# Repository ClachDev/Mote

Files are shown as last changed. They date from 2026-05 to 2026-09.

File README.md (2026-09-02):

# Mote




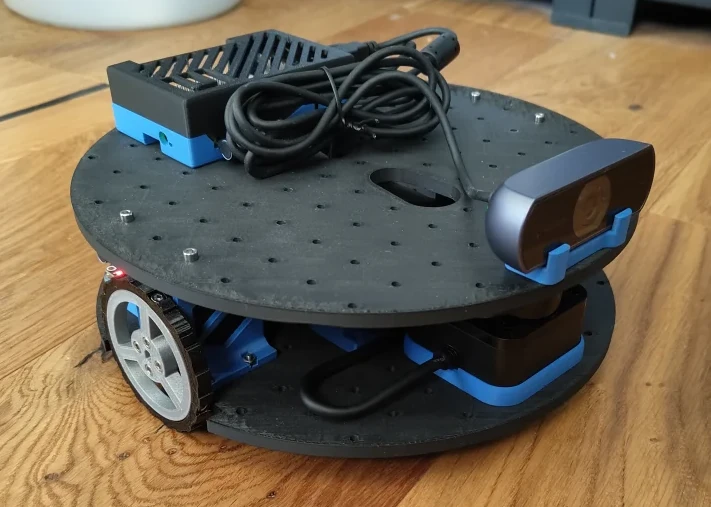
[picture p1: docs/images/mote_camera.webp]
Mote with camera


This readme covers the basics of Mote and how to use it. The full user docs including build instructions, etc, can be found [here](https://clachdev.github.io/Mote/).

## *Mote*vation (I'm sorry I had to!)

While working on some libraries I really needed a simple robot platform to test
them out on. There are some existing platforms but they are either too expensive
(turtlebot 3), or much too expensive (turtlebot 4). Some are cheap but lack
sensors (LeKiwi).

When I started out in robotics there was a [$50
robot](https://www.societyofrobots.com/step_by_step_robot.shtml) project I
followed. That was made for a different age but I figured why not see how
cheaply I can make a fully functioning robotics platform for today's enthusiasts.

The main factors I've engineered for are:

1. it must be as **cheap** as operationally possible - if it isn't affordable the
   project loses purpose.
2. it must be able to run **ROS** - you should be able to use this platform to run a
   normal ROS stack to map and navigate around a home or office.
3. it must be compatible with cutting edge PhysicalAI platforms like **LeRobot** -
   ROS is good but the future requires experimentation
4. it should follow the [Open Robotic
   Platform](https://openroboticplatform.com/designrules) standard - robots are
   more fun if you tinker about and add arms.

I've taken a lot of inspiration from projects like
[LeKiwi](https://github.com/SIGRobotics-UIUC/LeKiwi) which aim to be accessible
and [ORP](https://openroboticplatform.com/) which wants interoperability.

Apart from allowing me to test algorithms, I also want Mote to be a comparison
platform between classical ROS/Nav2 navigation and learned policies via
[LeRobot](https://github.com/huggingface/lerobot).

Finally, I also want to take this project further than just getting a robot running.
I want to use it to explore and act as a reference for what a full robotics
stack might look like: versioned maps, zones, remote operation, and maintaining
a multi-robot fleet.

See [`design/`](design/) for hardware design decisions, requirements, and bill
of materials.

## Hardware

The main hardware components are below with the Raspberry Pi and the battery
being the biggest cost factors (see [the BOM](design/BOM.md) for the full
hardware list).

- Raspberry Pi 5 (4GB) - Linux so we can run ROS, 4GB because memory is crazy expensive these days
- 5V USB-C power bank (slim form factor, ≥85W dual output) - Easy, cheap, and simple to integrate power supply
- 2× Feetech STS3215 servo - this simplifies our logic and standardises on components used by the [SO-101 arm](https://github.com/TheRobotStudio/SO-ARM100)
- Waveshare Serial Bus Servo Driver Board - Needed to connect servos to the pi.
  If using the SO-101 arm you can share a single board.
- SLAMTEC RPLIDAR C1 - The cheapest LIDAR I could find.
- USB webcam - Need some vision for LeRobot to function. Also helps with teleoperation.

I've tried to keep as many of the components 3D printed as possible to keep it
accessible. In theory some parts of the chassis can be CNC'd but I don't have
the ability to test and iterate on that right now.

## Software

Built with ROS2 Jazzy, managed via [pixi](https://pixi.sh). This gives us a nice
way to package everything up without worrying about ecosystem concerns — no
system ROS install needed, on the Pi or your workstation.

| Package | Purpose |
| --- | --- |
| [`mote_bringup`](mote_bringup/) | Launch files, site management, health monitoring, provisioning, etc |
| [`mote_description`](mote_description/) | URDF robot model and `robot.yaml` |
| [`mote_hardware`](mote_hardware/) | ros2_control hardware interface |
| [`mote_nav`](mote_nav/) | Nav2 plugins |
| [`mote_perception`](mote_perception/) | Image processing pipeline (needs a separate "inference" machine) |
| [`mote_tasks`](mote_tasks/) | Behaviour-tree task layer |
| [`mote_arm`](mote_arm/) | SO-101 arm driver |
| [`mote_fleet`](mote_fleet/) | Fleet control plane: fleet server, operator dashboard, map registry |
| [`mote_simulation`](mote_simulation/) | Gazebo sim, a world ladder, and the smoke test (workstation only) |

I'm trying to keep all dependencies from
[Robostack](https://robostack.github.io/index.html) or `conda-forge`. Anything
else belongs as a git submodule moving to either `conda-forge` or the
`prefix.dev/mote` channel once condafied/pixified.

## Build & Setup

### Prerequisites

- A Raspberry Pi 5 running 64-bit Linux (Ubuntu 24.04 or Raspberry Pi OS
  Bookworm both work) - set up with [Raspberry Pi
  Imager](https://www.raspberrypi.com/software/) -> Raspberry Pi OS Other ->
  Raspberry Pi OS Lite.
- [pixi](https://pixi.prefix.dev/) installed. Everything else (ROS 2 Jazzy,
  Nav2, drivers) is pulled in by pixi, so you don't need a system ROS install.
- The robot assembled with the servos and sensors wired to the Pi.

**Note:** The build commands (1 and 2) can be run on your developer machine for
testing, but 3 onwards requires the real hardware connected so must be run on
the Pi.

### 1. Clone

```bash
git clone --recurse-submodules https://github.com/ClachDev/Mote
cd Mote
```

(Forgot `--recurse-submodules`? `pixi run submodules` fetches them afterwards.)

### 2. Build

```bash
pixi run build
```

If you run these on your developer machine, sync the code to the Pi with
`pixi run sync`.

### 3. Setup Pi

There are a few setup tasks that must be run on the Pi before first use. These
set up udev rules, systemd services, and other configuration. It should only
need to be run once.

```bash
pixi run setup
```

### 4. Configure the servos

The drive wheels are expected at servo IDs **7** (left) and **9** (right) at
1 Mbaud. Fresh Feetech STS3215 servos ship as ID 1, so you'll need to assign
IDs before first use. Run the guided setup and connect one servo at a time when
prompted:

```bash
pixi run setup-ids
```

### 5. Map, then drive

The stack is split into two phases: an initial SLAM mapping phase and then a
non-SLAM drive phase.

To use SLAM to generate a map:

```bash
pixi run mapping   # bringup + SLAM: drive around (teleop or nav goals) to build a map
pixi run save-map  # save the map + posegraph into the active site
```

With a map saved you can just run the robot stack (no slam):

```bash
pixi run robot     # bringup + Nav2: drive the saved map autonomously
pixi run teleop    # Manual keyboard teleoperation, any time
```

You can also run a Foxglove desktop to connect to the robot over websocket at
`ws://<robot-id>:8765`. The layout is defined in
`mote_bringup/foxglove/mote.json`.

Maps live in **site bundles** under `~/.mote/sites/`.

**Congratulations! At this point you should have a working robot stack: maps,
SLAM, Nav2, and teleop.**

The longer version of all of the above — provisioning a clean Pi, what a site
bundle holds, the systemd services, naming zones and running missions — is
[Getting started](https://clachdev.github.io/Mote/getting-started/) on the docs
site.

## Simulation (no hardware required)

A Gazebo simulation of Mote runs the same controllers, same scan pipeline, and
crucially the *same launch files* as the real robot, so nothing can drift
between sim and hardware. The sim dependencies live in a separate pixi
environment so the robot install stays lean:

```bash
pixi run sim            # headless gz + robot + controllers
pixi run sim-test       # ~20 s headless smoke test (drive + odom + scan + map)
pixi run -e sim -- gz sim -g   # optional: attach the Gazebo GUI
```

The worlds in `mote_simulation/worlds/` form an easy-to-hard ladder, selectable
with `world:=` (e.g. `pixi run sim world:=hospital_world.sdf`):

- **`mote_world.sdf`** (easy) — a simple walled room; the default and the
  `sim-test` world.
- **`office_world.sdf`** (medium) — a corridor of identical rooms that
  stresses localisation.
- **`hospital_world.sdf`** (hard) — a ~58×38 m hospital with a looping
  corridor grid, ~50 rooms, and clutter.

## Perception

Rather than add a £150 RGB-D camera to the build, I've been trying to make use of a
single cheap webcam plus some smart vision models. The perception stack is
mostly offloaded to a separate "inference server" which runs somewhere with
access to a (cheap) GPU. This allows us to extract depth, tag objects, and
generally navigate as if we had a full 3D camera on board.

- **Depth Anything V2** — monocular depth, rescaled against the lidar per frame,
  feeds Nav2 a point cloud of the low obstacles the lidar plane can't see.
- **Open-vocabulary** — "red mug" becomes a map pose for the fetch
  mission, with no training.

I'm still experimenting with this to see how far we can push it. How the
inference machine is chosen, deployed and scaled — and what the robot does when
it isn't there — is
[The inference server](https://clachdev.github.io/Mote/inference-server/).

## SO-101 Follower Arm

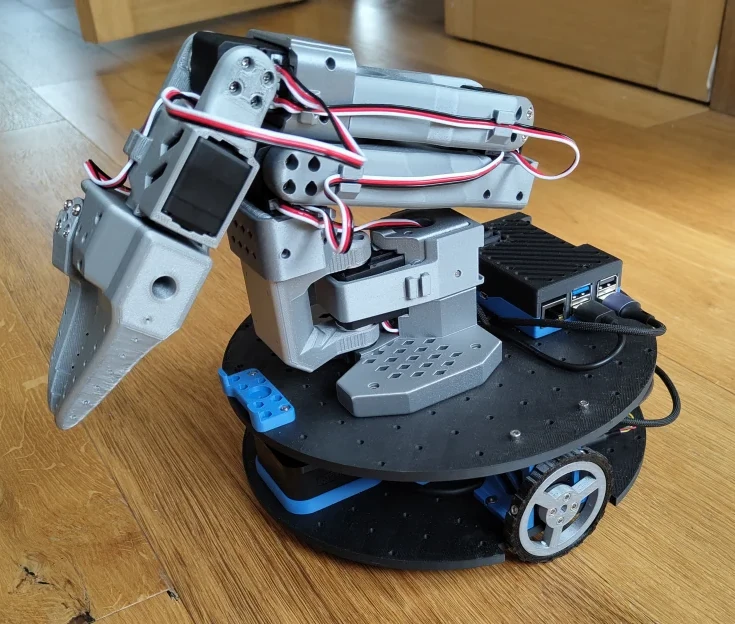
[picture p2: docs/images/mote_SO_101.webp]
Mote with SO-101 arm


The chassis is compatible with the [SO-101 follower
arm](https://github.com/TheRobotStudio/SO-ARM100) via the ORP mounting grid and
a custom base (see the SO-ARM100 project for the arm's BOM and assembly). The
arm shares the drive wheels' servo bus, so it needs no extra electronics.

I've started integrating it into ROS in [`mote_arm`](mote_arm/), covering the
driver, per-joint jogging, guided calibration that measures each joint's real
travel, and taught named poses.

## Fleet

I'm currently working on the beginnings of a fleet layer based on Tailscale and
MQTT. This is heavily work in progress but here's a little preview:

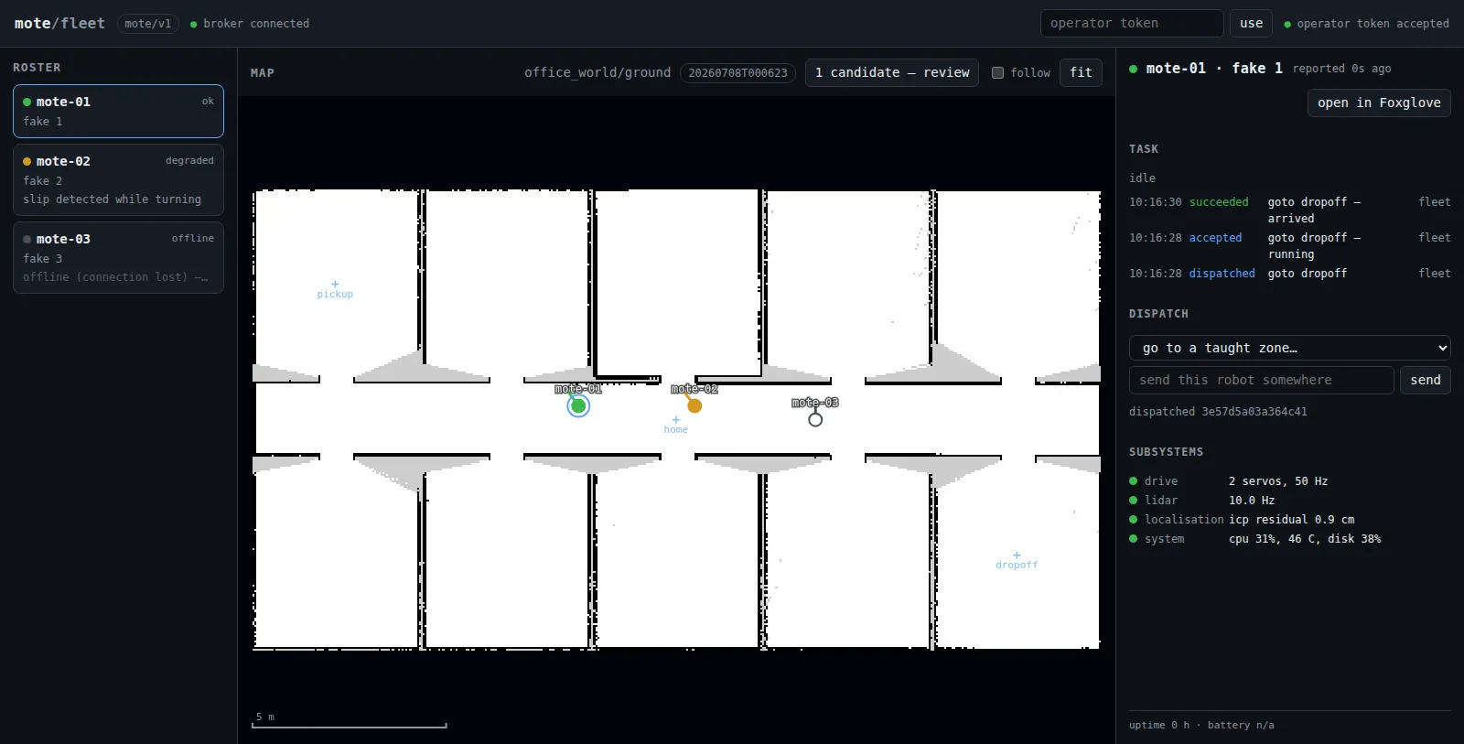
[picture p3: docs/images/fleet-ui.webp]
Fleet dashboard


The operator's side of it — overlay, enrollment, the dashboard, dispatch and
the map registry — is the
[fleet runbook](https://clachdev.github.io/Mote/fleet/).

## Contributions

This project is still in its early stages and I'm happy to accept contributions
of any kind. AI _aided_ contributions are also welcome but only if you can explain
and vouch for every change!

A [pre-commit](https://pre-commit.com/) config handles quick hygiene checks,
shell linting (shellcheck) and Python error checking (ruff). Enable it once per
clone, and it runs automatically on commit:

```bash
pixi run lint-install   # wire it into .git/hooks (one time)
pixi run lint           # or run across the whole tree manually (~1 s)
```

The [docs site](https://clachdev.github.io/Mote/) is built from this repo with
mkdocs, and mounts each package's own README rather than copying it — so
documentation is edited beside the code it describes:

```bash
pixi run docs           # live-reloading site on http://127.0.0.1:8000
pixi run docs-build     # what CI runs, with --strict
```

## Sponsorship

If you want to help me test new sensors or components to lower the cost even
further please consider sponsoring the project and I'll recognise you or your
company here!

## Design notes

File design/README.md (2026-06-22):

# Mote Design

## Design Decisions

### Chassis diameter: 235mm

The chassis uses a 235mm circular plate, adapted from the [ORP 360mm circular
plate](https://openroboticplatform.com/part:12). 235mm fits comfortably on a
standard 256mm 3D printer bed and gives a good outer hole layout from the ORP
grid — 240mm places holes right at the plate edge, and 250mm+ would be tight on
the bed. All components fit within the 235mm footprint, and the power bank
(152mm longest dimension) fits comfortably within the circle.

### Power: 5V only

Mote standardises on 5V (USB-C power bank) and does not offer a 12V variant.
The 12V config requires a DC-DC converter to power the Pi, adding cost and
complexity. A power bank outperforms a typical 12V Li-ion pack on
capacity (~100Wh vs ~60Wh), charges via standard USB-C, and has a built-in BMS.

The power bank directly connects to the Pi (USB-C to C) and the MCB (USB-C to C
to DC).

### Power bank form factor

The power bank is sandwiched between the two lower chassis layers to keep the
centre of mass low. The servo height is 45.2mm and the lidar is 41.3mm. For some
extra space and nice numbers I've buffered the standoffs to 50mm. This is then
the limiting factor in choosing a power bank. I've found that availability
changes depending on country so the most important thing to look for is a height
less than 50mm, and two USB-C ports. I found that with the UGREEN 140W bank
which advertises 100W on In/Out1 and 45W on Out2, I need to connect the MCB to
Out1 to stop them stalling. The Pi runs fine on the 45W port.

## Requirements

- Only two motors with differential drive. This matches real robots more closely
  than the three motors LeKiwi has.
- Normal wheels, not holonomics. Those are noisy and expensive.
- The wheels should be centered and inset so the footprint is circular.
- The chassis should follow the [ORP](https://openroboticplatform.com/) standard
  for interoperable parts.
- Standard sensor configurations
  - Camera
  - Lidar
- It should use "standard" parts, i.e. either Dynamixel or Feetech servos.
- The chassis should be compatible with the SO-101 arm from TheRobotStudio.
- Mote is intended as a comparison platform between the classical ROS/Nav2
  navigation approach and the LeRobot learned policy approach.

## Bill of Materials

See [BOM.md](BOM.md).

## Build guides

- [WIRING.md](WIRING.md) — connections, power topology and budget, IMU pinout.
- [ASSEMBLY.md](ASSEMBLY.md) — print settings per part and assembly steps.

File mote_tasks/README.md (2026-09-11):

# mote_tasks

The task layer: behaviour trees ([py_trees](https://py-trees.readthedocs.io))
that sit on top of Nav2 and sequence missions. Two missions today — *fetch*,
the skeleton of "pick things up off the floor and take them somewhere", and
*goto*, place-based navigation ("go to the kitchen"):

```
fetch (Sequence)
├── wait_for_task      idle until a command arrives
├── acquire_object     zone target: pass through; label target: ask the detector
├── drive_to_object    Nav2 NavigateToPose to the object pose
├── pick               stub — the SO-101 arm slots in here
├── drive_to_drop      Nav2 NavigateToPose to the drop pose
└── place              stub

goto (Sequence)
├── wait_for_task      idle until a command arrives
└── drive_to_zone      Nav2 NavigateToPose to the zone's pose
```

`task_server.py` hosts both trees and dispatches on the command's first word
(`fetch` / `goto`); an unknown word is rejected. `WaitForTask` and the shared
`task` blackboard key live in `trees/common.py`.

py_trees is pure Python (a pixi PyPI dependency); the ROS glue is ours and
deliberately small: `task_server.py` ticks the tree on a timer, and
`behaviours/nav.py` wraps the Nav2 action client as a behaviour. There is no
py_trees_ros dependency (it isn't packaged for robostack, and this glue is
~100 lines).

## Running

```bash
# Terminal 1: sim with SLAM + Nav2 (no saved map needed)
pixi run sim-mapping

# Terminal 2: the task server (zones default to mote_world coordinates)
pixi run tasks use_sim_time:=true

# Terminal 3: give it a job, watch the status
pixi run -- ros2 run mote_tasks mission --list      # what it will accept
pixi run -- ros2 run mote_tasks mission fetch target=pickup destination=dropoff
```

On the real robot, run `pixi run tasks` alongside `pixi run robot`. Zones
belong to the active site (see the Sites section in CLAUDE.md). Geometry gets
there three ways: `pixi run save-zone <name>` captures the pose the robot is
standing at, `pixi run segment-map` reads room outlines off a saved map, and
the fleet dashboard's zone editor places them on a candidate revision, which a
promotion then hands to every robot at the site. Only `save-zone` proves the
pose is reachable, by having driven to it; the other two put a coordinate on
the map and leave that to the planner. `tasks_launch.py` resolves the active
site's zones automatically, falling back to the committed
`config/zones.default.yaml` (which also documents the format).

## Zones, and "go to the kitchen"

A **zone** is the one named-place concept: a pose in the map frame that the
robot can navigate to. `fetch` uses zones as its `pickup`/`dropoff`
waypoints, and `goto <zone>` drives to any of them — `goto kitchen`,
`goto home`, whatever is in the table. A zone can *optionally* carry an **area
footprint**, which turns it from a bare waypoint into something that also
answers "am I inside it?". That footprint is just optional metadata on the
single zone concept — not a second kind of thing — so there's one loader
whatever wrote the file.

A floor stores this in one `zones.yaml`, and the floor owns it: a zone is a
coordinate in the floor's frame — a fact about the building — where a map
revision is an estimate registered into that frame.

```yaml
frame_id: map
zones:
  pickup:  {x: 1.8, y: -1.5, yaw: 0.0}      # bare waypoint
  kitchen: {x: 2.0, y: 2.0, radius: 1.5}    # room: pose + circular footprint
  ward:    {x: 6.0, y: 1.0,                 # room: pose + outline
            polygon: [[4, 0], [9, 0], [9, 3], [4, 3]]}
```

`goto kitchen` navigates to the pose; success is exactly Nav2 reaching it —
the footprint isn't needed for `goto`. `zones.load_zones(path)` returns
`{name: Zone(name, pose, footprint)}`, and `zones.containing(zones, x, y)`
answers "which zone am I in?" (nearest-pose first) using the footprints.

### Circles and polygons

A `radius` is the simple default — one number, and `pixi run save-zone <name>
--radius R` writes it along with the pose. It only describes a roughly round
room, though. A real ward is a rectangle, a ward with an ensuite is an L, and a
corridor stretch is a long thin box; sizing a circle to fit inside one of those
leaves most of the room outside the zone, and sizing it to cover the room
spills into the neighbours. Concretely, the hospital world's wards are 4.7 x
5.6 m — the `radius: 1.5` circle they used to carry claimed 7.1 m² of a 26.5 m²
room, so standing 2 m inside the kitchen answered "you are in no zone".

A `polygon` is a list of `[x, y]` vertices in the file's `frame_id`, closed
implicitly, in either winding order, and may be concave — membership is a ray
cast, not a convex-hull test. A zone carrying both keys uses the polygon.

Polygons do not come from driving. `pixi run segment-map` reads them off a
saved map, and the fleet dashboard's zone editor draws and drags them on a
candidate revision — which is also why a polygon zone may omit `x`/`y`: the
loader then derives a pose guaranteed to lie inside the outline (the centroid,
or, when the shape is concave enough that its centroid falls outside, the
middle of the widest span through it). Where a pose *is* given it always wins,
which matters: in the hospital wards the room centre is occupied by a bed, so
the pose is the doorway approach.

Because polygons arrive from a different direction than poses do, re-capturing
a room's pose with `pixi run save-zone <name>` keeps whatever footprint the
zone already had; passing `--radius R` is the deliberate way to replace it.
Zones are written into the active site's floor (`site info` shows the zone
count, how many have a footprint, and how many names have no geometry here at
all), or the legacy `~/.mote/zones.yaml` when no site is active.

## Interface

All three topics are `std_msgs/String` carrying JSON. A custom message would
have bought type-checking inside the ROS graph and cost the property that
matters more: the fleet agent forwards these payloads to MQTT byte for byte, so
there is one definition of the wire and the bridge cannot reinterpret it.

- `task/capabilities` — a **capability/v0 capability set**, published latched:
  what this robot can be asked to do, with a JSON Schema per input.
  `mote_tasks/capabilities.py` is the authority. Two keys, both from the
  specification's standard registry:
  - `goto` with `{"target": "<zone>"}` — drive to a named zone's pose.
  - `fetch` with `{"target": "<zone or label>", "destination": "<zone>"}` — a
    `target` matching a zone name drives straight there; anything else is an
    **open-vocabulary object label** (underscores become spaces, so
    `red_box` looks for "red box") resolved by the perception stack's detector
    — run `pixi run perception` (the node) and `pixi run inference` (its
    server) alongside the mission (see mote_perception's README, L2).
- `task/command` — a **mission/v0 mission command**: a capability key, a typed
  input, and a correlation id the dispatcher chose.
- `task/status` — a **mission/v0 mission status** per transition:
  `dispatched` (published by the agent) / `accepted` / `succeeded` / `failed` /
  `rejected`, the last two carrying a typed `failure`.

The failure is the point of the typing. `rejected` says `unknown_capability`,
`invalid_input` (naming the property), `busy` (naming the mission holding the
lane), `precondition` or `unresolved_zone` (carrying zone/v0's own reason);
`failed` says `obstructed`, `unreachable`, `timeout` or `internal`, and the
behaviour that failed is what decides which — see `trees/common.py`'s
`report_failure`. Each carries `recoverable`, so a dispatcher retries or does
not without reading prose.

**This node owns the lane.** One mission at a time per lane; a second is
rejected with `busy`. It also evaluates the capability's blocking preconditions
before accepting — `localized` wants a `map`→`base_link` transform, `zone_known`
wants the zone to resolve — and enforces `max_duration_s`, failing a mission that
overran with `timeout`. An unmet *non-blocking* precondition is reported in
`warnings` on the `accepted` status rather than refusing, so a mission that
started degraded is visible.

Label missions go through `behaviours/perception.py`'s `AcquireObject`: it
publishes the label to `detect/labels`, waits for a matching detection on
`detected_objects` (vision_msgs/Detection3DArray, map frame), and writes a
**standoff goal** — 0.4 m short of the object, facing it — to the same
`object_pose` blackboard key the zone path fills in directly. The rest of the
tree cannot tell the difference. The label is cleared on the way out so the
detector idles between missions.

## Where this goes

- **Search**: `acquire_object` currently needs the object visible from where
  the robot stands; a search behaviour (spin in place, tour zones) slots in
  ahead of it.
- **Arm**: `pick`/`place` stubs become real behaviours talking to the SO-101
  (same STS3215 bus as the wheels).
- New missions get their own tree under `trees/`, composed from the shared
  behaviours.

## Testing

`pixi run test` runs the tree tests against a mock `navigate_to_pose` action
server — `test/test_fetch_tree.py` (a full fetch tick), `test/test_fetch_object.py`
(fetch-by-label against a mock detector), and `test/test_goto_tree.py` (a goto
tick, plus command dispatch) — and the pure parser/loader tests
(`test_parse_command.py`, `test_goto_command.py`, `test_zones.py`, which covers
zone footprints and `containing`). No Gazebo, Nav2, or detection server needed.

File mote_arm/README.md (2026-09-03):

# mote_arm

Bring-up for the **SO-101 follower arm**: joint-state publishing, safe
joint-level control, and bench tools. This is the foundation for teleop /
episode recording and for replacing the fetch tree's pick/place stubs. There is
**no leader arm** — nothing here assumes leader-follower teleop.

## Stack decision: direct Feetech control (not LeRobot)

The task weighed **LeRobot** (native SO-101 support, calibration flow, dataset
format) against **direct Feetech control** (reuse the existing SCServo/servo
stack). We chose direct Feetech control:

1. **Same servos as the wheels.** The SO-101 uses Feetech STS-class servos on a
   serial bus — exactly what `mote_hardware` already drives via the vendored
   SCServo SDK. Position control, torque enable/disable, and feedback are a
   handful of register reads/writes we already understand. Reuse beats a new
   stack.
2. **LeRobot fights the lean Pi environment.** LeRobot pulls in `torch` and a
   large ML stack. The repo deliberately keeps `torch` *off* the Pi — depth and
   detection inference run in separate off-board `inference` pixi envs. Pulling
   that onto the Pi purely to move servos over serial is disproportionate. Our
   only new dependency is `feetech-servo-sdk` (`scservo_sdk`) — pure Python,
   aarch64-clean, the same SDK LeRobot itself uses under the hood, so this does
   not foreclose a LeRobot path later.
3. **Episode recording has a ROS-native path.** The repo already records
   provenance rosbags (`record_launch.py`). Teleop/episode capture can ride the
   same mechanism; we don't need LeRobot's dataset format to unblock the
   follow-up. If we later want that format for learning, we can convert bags or
   run LeRobot off-board.

   *That follow-up has since landed, and off-board is what it does* — the robot
   writes a stdlib-only capture and `tools/lerobot_export.py` converts it into a
   real `LeRobotDataset` in a linux-64 environment of its own. See
   [TELEOP.md](TELEOP.md). The decision above is unchanged: LeRobot is where the
   dataset goes, not where the arm is driven from.
4. **We can borrow the calibration flow without the framework.** LeRobot's
   `lerobot-calibrate` is two phases — write each servo's homing offset so
   mid-travel reads 2048, then record every joint's range in one sweep — and
   both are plain register operations on a bus we already drive. `pixi run
   arm-setup calibrate` implements that flow directly (see `BENCH.md`).

Everything hardware lives in `mote_description/config/robot.yaml` (`arm:`
section): the single source of truth for the port, baud, servo IDs, per-joint
soft limits, zero offsets, and direction.

### Why not an existing ROS 2 SO-101 stack?

Several exist and were reviewed (July 2026):

- [`legalaspro/so101-ros-physical-ai`](https://github.com/legalaspro/so101-ros-physical-ai)
  — the fullest arm stack: Feetech ros2_control driver, MoveIt 2, episode
  recording with LeRobot dataset export, torch isolated off the control path.
  Jazzy. But it is a **standalone arm on its own bus** and its teleop assumes a
  leader arm; we have neither.
- [`brukg/so_arm_100_hardware`](https://github.com/brukg/so_arm_100_hardware)
  — SO-100 ros2_control hardware interface; same standalone-arm shape.
- [`adityakamath/lekiwi_ros2`](https://github.com/adityakamath/lekiwi_ros2) —
  the closest platform to Mote (the LeKiwi mounts an SO-101 on a mobile base,
  and our servo IDs — arm 1-6, wheels 7/9 — follow its convention). As of this
  writing it drives the base and a pan-tilt payload only; its SO-101
  integration is planned, not shipped.

None of them address what dominates this package: the arm **sharing a serial
bus with the drive wheels** — bus ownership, ID collision, and the single-opener
guard. That problem has no shipped public solution, which is why `mote_arm`
exists rather than a dependency.

We are not outside this ecosystem either: `mote_hardware` builds on our fork of
[`adityakamath/SCServo_Linux`](https://github.com/adityakamath/SCServo_Linux)
(packaging fixes upstreamed, v1.0 packaged on the mote prefix.dev channel) —
the same SDK LeRobot and the stacks above sit on. Arm control has since folded
into `mote_hardware`'s ros2_control interface (below);
[`adityakamath/sts_hardware_interface`](https://github.com/adityakamath/sts_hardware_interface)
does the same job on the same SDK, with mixed position/velocity modes on one
bus, and remains the upstream to converge on — but it targets Kilted (we run
Jazzy), is not on rosdistro, and is a fast-moving single-maintainer WIP, so
adopting it now would trade a working stack for a moving one.

## Wiring: the arm shares the drive-wheel bus

Verified on the robot: arm servos are IDs **1–6**, the drive wheels are **7**
and **9**, and all eight are on the one `/dev/mote_servos` (CH343) bus. The arm
needs no udev rule of its own.

A serial port has no kernel-level exclusion, so a second opener is not refused —
it interleaves packets on the bus that *moves the robot*, and both openers see
corrupt replies. There is therefore exactly one process allowed to hold that
port, and **it is the controller_manager**: `mote_hardware`'s `MoteHardware`
exports velocity command interfaces for the wheels and position command
interfaces for the six arm joints, from one `open()`.

That is what lets the arm move *during* a mission, with Nav2 driving the wheels
at the same time — the point of the arm, and impossible while it lived in its
own process. Two guards keep the arrangement honest rather than merely
documented:

- **ID collision** — an arm ID equal to a wheel ID would send arm commands to a
  wheel. Rejected at load time in `mote_arm.config` *and* in `MoteHardware`, on
  both sides of the language boundary.
- **One opener only** — `MoteHardware::on_activate` scans `/proc` for another
  holder of the port and refuses to start, naming the PID; the read-only bench
  tools (`arm-setup check`, `arm-setup gains`) do the same through `mote_arm.bus`. So
  whichever starts first wins and the loser says why, instead of two processes
  quietly corrupting each other's traffic.

The bench tools still open the bus directly, so they still need the control
stack stopped (`pixi run kill`): `arm-setup check`, `arm-setup gains`, `arm-setup calibrate` and
`arm-setup offsets`. `arm-teleop` and `arm-pose` do not — they command the controller.

### Where the calibration enters

`zero`/`min`/`max` are measurements of one physical arm, so they live in
`$MOTE_HOME/arm.yaml` and robot.yaml carries only conservative placeholders
(see "`zero` and `home` are different things" below, and `arm-setup calibrate`).
The hardware enforces the soft limits, and the hardware reads them from the
URDF — so the URDF has to carry the *calibrated* numbers:

```
robot.yaml arm:  (defaults: ids, names, direction, gains)
        +
$MOTE_HOME/arm.yaml  (this arm's measured zero/min/max)
        |
        v  mote_arm.config.load() — the one implementation of the overlay
  launch_utils.resolved_arm()
        |
        v  written out, passed as xacro's `arm_config:=`
  <ros2_control> joint <param>s  ->  MoteHardware's clamp
```

xacro cannot resolve `$MOTE_HOME` or apply the overlay, so the launch does it
and hands over the answer. A bare `xacro mote.urdf.xacro` (for checking
generation) falls back to the packaged placeholders — never drive a calibrated
arm from that URDF, because calibration *moves the zero*, so the same radian
value names a different physical position.

## Where the arm lives in the control stack

```
robot.yaml (arm:)
   |
   +-- mote.urdf.xacro  -> <ros2_control> joints, one per arm servo, carrying
   |                       its id / soft limits / home / invert as <param>s
   |
   +-- mote_launch.py   -> arm_controller's joint list (never duplicated in
                           controllers.yaml)

controller_manager
   |-- diff_drive_controller   (active)    velocity -> wheels
   |-- joint_state_broadcaster (active)    /joint_states, wheels *and* arm
   \-- arm_controller          (INACTIVE)  position -> arm, on demand
```

`arm_controller` is a `JointTrajectoryController`, spawned **inactive**.
Activating it is what claims the arm's position command interfaces, which is
what makes the hardware enable torque — so "the arm is limp until something
asks it to move" is now a property of the control stack rather than a rule the
driver had to remember.

The hardware also spends the shared bus carefully, because the wheels are on
it: arm states are read one joint per control cycle (~8 Hz per joint at the
50 Hz update rate) rather than six reads every cycle, and arm goals go out as a
single sync-write packet, only when a goal actually changed. An idle arm costs
no bus traffic at all.

## Components

All bus I/O is isolated in `bus.py`; the config maths in `config.py` is
ROS-free and unit-tested (`test/`), so the safety-critical clamping and
conversions are verified without hardware.

| Piece | What it is |
|---|---|
| `config.py` | Parses the `arm:` section; encoder<->radian conversion + soft-limit clamping. |
| `bus.py` | `FeetechBus` — thin `scservo_sdk` wrapper (ping, read position/health, torque, position goal, homing offset). Lazy SDK import. |
| `control.py` | The one place that knows how to talk to `arm_controller`: single-point trajectories, and activation as the torque switch. |
| `cli.py` | The plumbing every arm CLI shares: strict argument parsing with ROS's own arguments cut out first, and a shutdown that stops spinning before it destroys the node. Both are properties that fail silently otherwise — see "Exits and arguments" below. |
| `arm_launch.py` (in `mote_bringup`) | Bench bring-up — the same controller_manager, URDF and `controllers.yaml` as a mission, without the lidar/camera/Nav2. `pixi run arm`. |
| `arm_check` (tool) | Standalone enumeration + health + zero snapshot. Read-only, but opens the bus: run with the control stack stopped. `pixi run arm-setup check`. |
| `calibrate.py` / `arm_calibrate` | Two-phase range calibration: sweep every joint at once, centre its zero, save limits to `$MOTE_HOME/arm.yaml`. Owns the bus: control stack stopped. `pixi run arm-setup calibrate`. |
| `arm_offsets` (tool) | Read/back up/restore/set the servos' position-correction offsets. The recovery path if a calibration is interrupted. `pixi run arm-setup offsets`. |
| `poses.py` / `arm_pose` | Teach and replay named poses, and narrow limits to a working envelope. `pixi run arm-pose save\|list\|go\|limits\|delete`. |
| `mock_arm` (node) | The control stack's interface — trajectory topic and `switch_controller` — with nothing behind it, plus an optional synthetic camera, so teleop, recording and replay run on a workstation. `pixi run arm-mock`. |
| **teleop + episodes** | Keyboard teleoperation and LeRobot-format episode recording — `teleop.py`, `arm_teleop`, `episode_record`, `episode_replay`, `tools/lerobot_export.py`. Its own doc: **[TELEOP.md](TELEOP.md)**. |

## Exits and arguments

Two things every arm CLI needs, both of which fail *quietly* when hand-rolled,
so they live in `cli.py` and nowhere else.

**Destroying a node that `spin()` still holds aborts the process.** The
executor is pulled out from under itself and the interpreter calls
`std::terminate`: exit 134, `terminate called without an active exception`,
after the tool has already done its work. The fix is ordering — shut the
context down, *join the spin thread*, and only then destroy — which is what
`cli.shutdown(node, spinner)` is for. Measured on this arm's CLIs with no
hardware attached: the jog CLI (stdin closed) and `arm-pose list` each aborted 3 of 3
runs before, and exited 0 on 3 of 3 after. It is not a rare race — with no
stack running to talk to, it reproduced every time. `test_cli.py` watches a
child process's exit status, because nothing in-process can catch an abort.

**ROS's arguments arrive mixed in with the tool's own.** `ros2 run` hands the
executable the whole command line, so a plain `parse_args` rejects
`--ros-args` outright (`arm-pose list --ros-args -p use_sim_time:=true` used to
die with "unrecognized arguments") while the usual workaround,
`parse_known_args`, silently discards anything it does not recognise — which on
a *safety* flag means a mistyped `--max-travel` or `--speed` does nothing and
says nothing, and the arm moves under the default instead. `cli.parse` cuts the
`--ros-args ... --` block out first and then parses what is left strictly, so
ROS arguments pass through and a typo is still an error.

## `zero` and `home` are different things

Worth stating plainly, because the two were both called "home" until 2026-07-28
and it confused an operator at the bench:

| Term | What it is | Where it lives |
|---|---|---|
| **zero** | The encoder count that reads 0 rad. After calibration, the *middle of the joint's travel*. | `robot.yaml`, `arm.joints[].zero` |
| **home** | A taught *pose*, normally the arm's rest position. Nothing to do with 0 rad. | `~/.mote/arm_poses.yaml` |

So the jog CLI's command to drive a joint to 0 rad was `zero`, not `home` (`home`
still works and says so), and `pixi run arm-pose go home` moves to the rest pose.

## Where the soft limits come from

**`pixi run arm-setup calibrate`**, in two phases — the same shape as LeRobot's
`lerobot-calibrate`:

```
pixi run arm-setup calibrate                        # sweep, then centre the zeros
pixi run arm-setup calibrate --skip-homing       # ranges only; writes nothing
pixi run arm-setup calibrate --joints wrist_roll # redo one joint
```

You sweep the joints; everything else is automatic.

**Phase 1 — record the ranges.** You move every joint to both of its mechanical
stops, in any order, while one live table records **all six at once**. One Enter
ends it. The band emitted is the swept range pulled **inward** by `--margin`
(0.05 rad), because a hard stop is where the operator stopped pushing — a soft
limit has to sit short of it.

**Phase 2 — centre the zeros.** Each joint's 0 rad is moved to the *measured*
middle of the range just swept, by writing the servo's position-correction
register (EEPROM, `SMS_STS_OFS_L/H`, address 31). The servo reports
`present = actual - offset`, so this re-centres the joint's whole travel inside
the 0–4095 encoder frame. The arm can be left wherever the sweep ended.

**Why the centre comes from the sweep.** LeRobot's `calibrate()` opens with a
single `input("Move {robot} to the middle of its range of motion and press
ENTER")` and takes every motor's zero from that one pose. It is an awkward,
unbalanced position to hold all six joints in, and eyeballing the middle is less
accurate than the measurement the sweep is about to take anyway.

That ordering is *load-bearing for them*, though, not incidental:
`record_ranges_of_motion` is a plain `min`/`max` over raw positions with **no
wraparound handling at all**. Centring first is what guarantees the sweep never
crosses 0/4095, which is what makes plain min/max safe. Sweeping first, as we do,
means the sweep *can* cross it — so `SweepRecorder` unwraps, and the centre is
recovered from the unwrapped stream. The trade is a small heuristic (a jump of
more than half a revolution between samples is a crossing, which no hand-moved
joint can produce at 20 Hz) in exchange for deleting the awkward step. It also
means a wrapped sweep is handled rather than silently mis-recorded.

LeRobot is Apache-2.0, so borrowing their code would be permitted with
attribution; none is copied here — only the shape of the flow.

**Centring is what makes the limits describable at all.** A joint whose travel
straddles the encoder's 0/4095 boundary has a raw min and max that say nothing
about its real span, and no zero/limit pair in that frame can express it —
`rad_to_counts` clamps at the encoder edge. Measured on the real arm, **two of
six joints did exactly that** (`shoulder_pan` and `wrist_roll`). There is no
software workaround: the servo's own goal register is 0–4095 too.

Offsets are **modular** — `present = (actual - offset) mod 4096`, so an offset of
3056 and one of −1040 command the same thing. An arithmetic result outside the
register's ±2047 is therefore folded, never rejected. (Rejecting one aborted a
real calibration run before this was understood.)

It opens the serial bus directly, like `arm-setup check`, so run it with the driver
stopped: the driver reports radians about the very zero being replaced, and the
arm has to stay limp throughout. It asks before releasing torque (an unsupported
arm falls) and again before the EEPROM write.

Four things it refuses to guess at, rather than emit plausible-looking numbers:

- **Travel beyond one revolution.** A continuously-rotating joint has no stops
  to calibrate against and fits no single-turn frame. Reported as its own case,
  because unlike a wrap there is no remedy — leave it out with `--joints`.
- **A range too short to survive the margin at both ends.**

**A continuously-rotating joint is only detectable if you rotate it past a whole
turn**, which is the one case refused above. Rotated less, it is indistinguishable
from a joint with stops, and no threshold below a full turn helps: it would miss
most real cases while firing on a long-but-stopped joint. LeRobot sidesteps this
by hard-coding the SO-101's `wrist_roll` as a full-turn motor and skipping its
range entirely. This arm's `wrist_roll` measures 5.88 rad — 94% of a turn — so
whether it has real stops is worth settling by hand; if it spins freely, exclude
it with `--joints` and drive it in relative terms.
- Under `--skip-homing` only, where the zero is not being moved: **an encoder
  wrap**, and **a zero the joint could never reach** (a band excluding 0 rad —
  the defect in the pre-calibration `shoulder_pan` limits, whose
  `[0.010, 0.229]` does not contain 0). Neither can arise from the centred path,
  where the zero *is* the middle of what was swept.

**If it stops partway, the arm is recoverable.** The offset register lives only
in the servo, so overwriting it destroys the previous value. Before the first
write, the existing offsets are snapshotted to `~/.mote/arm_offsets_backup.yaml`;
each servo is then written, verified by read-back, *and* checked to have moved
its reading by exactly the delta written, before moving to the next. Any failure
stops immediately, names the servos already changed, and points at
`pixi run arm-setup offsets restore`. (An earlier version wrote without a backup and
died mid-run on a dropped serial read — hence both the snapshot and the guard in
`FeetechBus._read`, which turns a short reply into `None` instead of an
`IndexError`.)

Taught poses do not have to be re-taught: they are re-expressed about the new
zeros by exactly the shift the calibration computed, so each still points where
it always did, and the previous file is kept as `.bak`. Only a pose that lands
outside the new soft limits is named — that one was taught somewhere the arm
cannot reach, which is a decision rather than an arithmetic problem.

**It saves the result to `~/.mote/arm.yaml`** — per-robot state, not the repo —
and says so in one line. The numbers are not reprinted: the swept ranges were on
screen a moment ago, the limits are those pulled inward by `--margin`, and the
file itself keeps each value next to the measurement it came from.

That location is the point. Zeros and limits are measurements of *one physical
arm*: two robots with identical hardware have different ones, and the packaged
`mote_description/config/robot.yaml` is shared by the whole fleet and read-only
once installed from a channel. So the package keeps the *design* — ids, names,
direction, gains, and conservative defaults for an arm that has never been
calibrated — and `mote_arm.config` overlays this robot's measured
`zero`/`min`/`max` on top at load time. Delete the file to fall back to the
defaults. It is the same rule as `~/.mote/camera_calibration.yaml` and the site
bundles: `MOTE_HOME` is per-robot, the package is shared.

The file carries the measurement alongside the value — swept range, sample
count, margin, and the `homing_offset` written to the servo, which exists
nowhere else and is the only record if a servo is swapped. Writes go through a
temporary file, and the result is validated through `ArmConfig` before it lands,
because this is what supplies the soft limits that stop the arm.

**Taught poses are migrated for you.** A pose is stored as radians about the
zero, so moving the zero changes which physical position each number names — but
the correction is exactly the shift the calibration just computed, so the poses
are rewritten rather than re-taught. They keep pointing where they always did,
and the previous file is kept as `.bak`. A pose that would land outside the new
limits is reported rather than silently clamped: that means it was taught
somewhere the arm can no longer reach, which is a decision, not an adjustment.

**One confirmation, at the EEPROM write.** Everything else follows from having
run the command: torque is released without asking (the arm is already limp
unless a driver was killed outright, which is detected by reading the torque
register), and the result is saved without asking, since saving it is what the
command is for.

### The servo's own goal-range limits, which are not the soft limits

There is a fourth place a limit can live, and it is the only one that is not in
a file. EEPROM registers 9 and 11 (`Min_Angle_Limit` / `Max_Angle_Limit`) fence
which goal positions a servo will accept. A goal outside the band is **refused
in silence**: no error, no status bit, no log line. The joint stops at the same
angle every time, in one direction only, whatever the load — which is precisely
what running out of torque looks like.

This arm arrived with five of six joints fenced inside their own travel, and it
cost an evening. `shoulder_lift` stopped dead at −0.865 rad against a
configured −1.7785, at 0% load, while the commanded position ran 0.8 rad past
it. Its `Min_Angle_Limit` read **1478**, and 1478 counts is −0.874 rad about a
zero of 2048:

```
joint            id    min   max   accepts (rad)      configured
shoulder_pan      1   1123  3079   -1.419 .. +1.582   -2.033 .. +2.033
shoulder_lift     2   1478  3859   -0.874 .. +2.778   -1.778 .. +1.778
elbow_flex        3    716  2941   -2.043 .. +1.370   -1.646 .. +1.646
wrist_flex        4    709  3075   -2.054 .. +1.575   -1.761 .. +1.761
wrist_roll        5      0   4095  -3.142 .. +3.140   -2.880 .. +2.880
gripper           6   2047  3510   -0.002 .. +2.243   -1.073 .. +1.073
```

**What set it: `lerobot-calibrate`, on the workstation, 2026-05-12.** The file
is still there —
`~/.cache/huggingface/lerobot/calibration/robots/so_follower/so101_follower.json`
— and its `range_min`/`range_max` are the six bands above to the count, beside
the `homing_offset` values the servos arrived with (2027, -1723, 1772, -1706,
-40, 1317). An earlier attempt sits next to it from the same morning
(`auldbot_arm.json`, 10:40) with `wrist_flex` still unswept at 0-4095.

LeRobot writes those registers from the range of motion it records, which is a
reasonable thing to do and is not what broke. **What broke is that
`arm-setup calibrate` then moved the zeros and left the fence where it was**, on
2026-07-28: a band in the corrected frame names different physical angles once
the offset under it changes, so the fence silently drifted onto the middle of
the joint's travel. Hence this tool writes the fence *and* the offset in one
run, and never one without the other.

Two of the six bands were already wrong when LeRobot wrote them, which is worth
knowing before trusting one. `wrist_roll` is unfenced because LeRobot hard-codes
the SO-101's `wrist_roll` as full-turn and skips its range. `shoulder_pan`'s
band is 760 counts narrower than its real travel, which is what an unwrapped
min/max `record_ranges_of_motion` yields for a joint whose sweep crosses 0/4095
— and `shoulder_pan` is one of the two joints here that do.

Two properties made it hard to see. The fence only binds under torque, so
`arm-setup calibrate` sweeps straight through it by hand and measures the full travel
— the calibration and the arm disagree, and only the arm is wrong. And the band
is compared against the *corrected* goal, so re-centring a zero moves what it
fences without changing a number anyone can read.

```
pixi run arm-setup limits show      # read-only: the band, in counts and radians
pixi run arm-setup limits clear     # hand every joint its whole 0-4095 range back
pixi run arm-setup limits restore   # write the as-found bands back
```

**The fence and the zero are now written by one run, and never one without the
other.** Phase 2 writes each joint's fence immediately after its own offset —
after, because the band is compared against the corrected goal and so means the
wrong angles until the frame has moved; immediately, because the pair is what
has to agree. Nothing is unfenced in between: a joint holds either its old band
or its new one, and the window where the two disagree is one bus transaction
wide. Both as-found sets are snapshotted first (`arm_offsets_backup.yaml`,
`arm_limits_backup.yaml`); neither exists anywhere else. `--skip-homing`
promises to write nothing to the servos, so it reports a cutting fence instead
of correcting it.

**The band written is the measured travel, not the soft limits** — wider by
`--margin` (0.05 rad) at each end. That is what makes it a backstop rather than
a second opinion: `arm.yaml` always binds first, so the fence can never be the
thing that stops the arm in ordinary use, and `arm-setup limits show` reporting a band
narrower than the configured one therefore means something is wrong rather than
meaning Tuesday. What it catches is a soft limit that has gone wrong — a
hand-edited `arm.yaml`, a URDF that never received one, a servo swapped under a
stale calibration — where the servo still refuses to drive past its own stops.

There is no `arm-setup limits set`. A *narrower* envelope belongs in `arm.yaml`, where
`arm-pose limits` already puts one and where three commands print it;
`arm-setup limits clear` exists to take the fence off while diagnosing, and `restore`
to put back whatever was found.

### Named poses, and narrowing the envelope

The base layer captures a map position by driving there and running
`pixi run save-zone`; the arm's analogue is `pixi run arm-pose`. Pose the limp
arm by hand, capture it, and later command it back:

```
pixi run arm-pose save reachy     # read-only capture of the current pose
pixi run arm-pose list            # taught poses, and how far the arm is from each
pixi run arm-pose go reachy       # the only command that moves; asks first
pixi run arm-pose limits          # emit limits spanning the taught poses
```

Poses live in `~/.mote/arm_poses.yaml` (`MOTE_HOME` overrides `~/.mote`) —
per-robot data, since a pose only means anything for one physical arm and its
calibration. A pose is recorded in radians about its joint's `zero`, so moving a
zero changes which physical position each number names — but `arm-setup calibrate`
applies exactly the shift it computed, so poses survive a recalibration without
being re-taught. Editing a `zero` by hand does not, and invalidates them.

`arm-pose limits` is **not** the calibration path. It widens *outward* from the
extremes of the taught poses, so it can only describe where the arm has already
been, and it never learns where the stops are: a joint that barely moved between
two poses gets a near-zero band. Its remaining use is the opposite direction —
**narrowing** to a working envelope on top of calibrated hard-stop limits, when
a task wants a joint held tighter than the mechanism allows. Take the hard stops
from `arm-setup calibrate` first; reach for `limits` only to pull them in.

The values committed in `robot.yaml` today still come from the old envelope
method, and are flagged as such in that file, pending a calibration pass on the
real arm (`BENCH.md` step 3).

`arm-pose go` prints the travel each joint will make and asks before moving.
There is no ceiling on the distance — see below for why the one there used to be
was removed.

It **streams** setpoints at 20 Hz rather than commanding the destination in one
jump, so the arm moves continuously at `--speed` (0.5 rad/s default) instead of
lurching between waypoints. Supervision is by *lag* — how far the arm trails the
setpoint it was given: sustained lag beyond `--max-lag` (0.15 rad) for
`--stall-time` means it is no longer keeping up, and the move stops where it is.
Measured lag on the full swing is a steady 0.07-0.10 rad.

`arm-pose go` and `arm-teleop` command `arm_controller`, so they run happily alongside
a mission. `arm-setup check`, `arm-setup gains`, `arm-setup calibrate` and `arm-setup offsets` open the
bus directly and so still need the control stack stopped — `MoteHardware`'s own
guard will refuse to start against them, and theirs will refuse to start against
it.

Lag is measured against `/joint_states`, which the hardware refreshes one arm
joint per control cycle to stay inside the bus budget it shares with the wheels,
so a stall is caught within a few setpoints rather than instantly.

**Whether the arm is held is read from the controller manager, not assumed.**
`go` leaves `arm_controller` active — that is what holding the pose means — so
the next command client starts against an arm that is already held.
`ArmControl` therefore asks `list_controllers` before its first switch, and
treats a STRICT refusal as success when the controller turns out to already be
in the state requested. Assuming `inactive` at construction made the *second*
`arm-pose go` of a session fail on every streamed setpoint: `Controller with
name 'arm_controller' is already active` / `Aborting, no controller is
switched!`, at 20 Hz. It also made the jog CLI's documented limp-on-exit silently
do nothing when something else had left the arm holding.

**A taught pose is stored reachable.** `save` clamps each joint into its soft
band and names the ones it held there. Posing by hand is posing a limp arm
against its stops, and the soft limits sit `--margin` (0.05 rad) inside those,
so a raw capture is routinely a fraction outside the band — measured at the
bench, `elbow_flex` 0.012 rad past and `gripper` 0.042 rad past. Stored raw,
such a pose can never be replayed: every `go` clamps it and says so, which is a
warning that arrives minutes late. A joint further out than the margin is
reported separately, because that means the arm and `arm.yaml` disagree about
where the limits are rather than that the operator leaned on a stop.

**`go` has no travel ceiling, and the one it had is gone.** `--max-travel`
defaulted to 0.35 rad, chosen when the packaged limits were the old `arm-pose
limits` envelope whose bands were ~0.2 rad — wider than a whole joint's range,
so it fired on nothing. Calibration gave the joints their real ~3.5 rad bands
and left it refusing the ordinary case: teach a pose, let go, watch the limp arm
fall to rest, replay.

Sizing it off the arm instead would have made it fire on nothing again, which is
worse than removing it: a flag, a help string and a test that all describe
nothing. And distance is not what makes a move risky once setpoints are
streamed. The arm advances at `--speed` whatever the distance, so a long move is
a slow move and not a violent one; `--max-lag` stops it if the arm falls behind;
the soft limits bound where it can go; and every move is confirmed unless
`--yes`. The distance limit was a proxy for the lurch that streaming removed,
and nobody removed the proxy.

`episode-replay` keeps a `--max-travel`, doing a different job: a long approach
there means the arm is not where the recording started, so the replay will not
reproduce it. That is a check on the episode, not on the motion.

## Torque policy

Nothing moves without an explicit command. The policy did not change when the
arm moved into ros2_control — it stopped being a rule the driver enforced and
became a consequence of who holds the command interfaces.

- **Bringup:** torque **OFF** — the arm is limp/back-drivable, and
  `arm_controller` is spawned inactive so nothing holds its interfaces. Have the
  arm physically supported or resting in a stable pose before power. A servo
  that fails enumeration, or cannot be *confirmed* in position mode (mode
  changes are verified by read-back, never blind-written to EEPROM), is excluded
  from control entirely: its state is still published, but it accepts no goals —
  in wheel mode a position goal is obeyed as a speed.
- **Taking hold:** activating `arm_controller` makes the hardware seed each
  joint's goal register with its *present* position and only then enable torque
  — the order that stops an arm snapping to a stale goal. It engages one joint
  per control cycle (~120 ms for all six) so no single realtime cycle pays for
  six read-plus-write pairs, and a joint whose position cannot be read stays
  limp rather than being driven against an unknown goal.
- **Letting go:** deactivating `arm_controller` (`arm-teleop`'s `SPACE`, or
  quitting it) drops torque immediately, inside the switch itself rather than
  on the next write — a component being torn down may never write again.
- **Shutdown:** deactivating the hardware stops the wheels and limps the arm.

Goals are soft-clamped to the per-joint limits from `robot.yaml` **in the
hardware**, on the far side of every client, so a trajectory controller, the jog
CLI and the task layer are all held to the same envelope. `arm-teleop` clamps again
client-side purely for immediate feedback.

## Control interfaces

- `/joint_states` (`sensor_msgs/JointState`) — published by
  `joint_state_broadcaster` for the wheels *and* the arm. robot_state_publisher
  animates the arm in TF from these (the joints are in the URDF; see
  `mote_description/urdf/mote.urdf.xacro`, `arm:=true`).
- `arm_controller/joint_trajectory` (`trajectory_msgs/JointTrajectory`) — a
  goal. `allow_partial_joints_goal` is on, so a single-joint trajectory is
  valid and the rest hold where they are.
- `arm_controller/follow_joint_trajectory` (action) — the same thing with
  feedback and cancellation; this is the seam the task layer's pick/place will
  use in place of its stubs.
- `controller_manager/switch_controller` — activate to hold, deactivate to limp.

## Physical note: the arm is mounted backwards (GitHub #2)

The camera and the arm fouled each other on the top plate. The arm is therefore
mounted **rotated 180 degrees**, which is option 1 of that issue: the camera
clears it — only just — and the price is reach in the forward direction.

Two consequences. `arm_mount_joint` in `mote.urdf.xacro` still carries
`rpy="0 0 0"`, so TF and RViz draw the arm facing the way it used to, not the
way it does; joint-space work (jog, taught poses, teleop, replay) is unaffected,
because none of it asks where the gripper is in the base frame, but anything
that does — a fetch standoff pose, an IK stack — would be 180 degrees out.
And the clearance is tight rather than comfortable, so re-check it after any
re-mount.

## Calibration

The committed `zero:` values are the arm's **as-found resting counts** read off
the robot, not measured mid-travel. A real calibration run showed why that is
bad: the parked pose sits within ~20 counts of a hard stop on `shoulder_lift`,
`elbow_flex` and `gripper`, so "0 rad" currently means "jammed against the
stop", and the committed bands (~0.2 rad) are a small fraction of the ~3.4–3.6
rad these joints actually travel.

See `BENCH.md` for the full runbook. In short:

1. `pixi run arm-setup check` — confirm every joint responds; note IDs.
2. `pixi run arm-setup calibrate` — sweep the joints, centre their zeros, save to
   `~/.mote/arm.yaml`. No rebuild: the file is read at load time, not compiled
   in. This sets `zero` *and* `min`/`max` together, which is the point: limits
   only mean something relative to the zero they were measured about.
3. Re-teach only the poses it reported as outside the new limits — the rest are
   migrated for you.
4. Step each joint (`pixi run arm-teleop`, `m` for step mode) and flip `invert` for any that moves
   opposite the expected sign. `invert` changes what the limits mean, so
   re-calibrate after changing it.

`arm-setup check --save-zero` still prints a bare `zero:` snapshot of the current
pose. It is a convenience, not calibration: it measures no range and writes no
offset, so the limits stay whatever they were.

## Verified on hardware

> **The ros2_control fold is not in this table.** Everything below was measured
> against the real arm on 2026-07-25, when it ran as a standalone driver. The
> move into `mote_hardware` is verified against a *simulated* STS bus —
> `mote_hardware/test/test_arm_bus.cpp` drives the real plugin through the real
> SCServo SDK over a pty and asserts on the actual packets (comes up limp, seeds
> the goal before enabling torque, clamps to the soft limits, sends nothing when
> a goal has not changed, drops torque on release) — plus a green `pixi run
> sim-test`. The hardware runs in `BENCH.md`'s "still open" list are the real
> gate, in particular jogging the arm *while the wheels are driving*, which is
> the thing this whole change exists to make possible.
>
> The soft limits did not change, and they are still the authoritative gate on
> motion — but they are still the conservative envelope of two taught poses,
> and `home:` is still the arm's as-found resting counts rather than a taught
> mechanical zero (see Calibration). Nothing here widens what the arm may do.

Run against the real arm on 2026-07-25:

| Check | Result |
|---|---|
| Bus enumeration | all 6 joints respond; 5.1–5.2 V, 26–29 °C, load 0 |
| `/joint_states` | 6 arm joints at a steady 20.0 Hz, no jitter while limp |
| Startup torque | bringup comes up limp; `TORQUE_ENABLE` reads 0 on every joint |
| Port guard | `arm_check` refused the bus while another process held it, naming its PID |
| Torque engage | seeding goals before enabling moved the arm **0.00000 rad** |
| Jog motion | `elbow_flex` jogged −0.05 rad per step and returned; `/joint_states` tracked |
| Soft-limit clamp | repeated `+` past the limit held at `+0.103` — no further motion |
| Shutdown | SIGINT exits 0, no traceback, torque off, port released |
| Pose replay | full `home` <-> `reachy` move (3.19 rad / 183 deg) completed both ways, streamed at 0.5 rad/s, lag steady 0.07-0.10 rad, settling within 0.026-0.041 rad |
| Servo gains | `arm-setup gains apply` wrote and verified Kp=32 on all six servos; temps unchanged at 27-30 C after the full move |

Gain tuning, on the same arm on 2026-07-28:

| Check | Result |
|---|---|
| Kp sweep (16/32/64/128) | droop confirmed across an 8x gain range; error 0.068 -> 0.008 rad at load 144-188 of 1000, no ripple or reversals at any gain |
| Repeatability | a second sweep reproduced every trial to 1-2 encoder counts |
| Larger step (1.0 rad) | same law, error 0.038 -> 0.004 rad; zero overshoot (the servo's speed profile decelerates into the goal) |
| Double speed (1000 steps/s) | still no overshoot, ripple or reversals, up to Kp=128 |
| Ki sweep (0/1/2/4/8 at Kp=64) | ki=8 reached 99.7% (error 0.001 rad) but settling went 0.46 s -> 2.12 s; left at 0 |
| Kp=64 applied | written and read-back verified on all six servos |
| Pose replay at Kp=64 | full `home` <-> `reachy` both ways, lag 0.05-0.08 rad, settling within 0.012-0.028 rad (was 0.026-0.041 at Kp=32); servo 22-24 C throughout |

`arm-pose go` streams setpoints continuously (see above) and stops when the arm stops keeping up, rather than holding against a load it
cannot overcome. At the shipped `Kp = 16` that guard correctly halted the
`reachy` replay after ~0.13 rad; with `Kp = 32` applied the same move runs to
completion.

## Position accuracy and the servo gains

The arm shipped with `Kp = 16` on every servo, which left a permanent
steady-state error under load: the servo settles where `Kp x error` balances the
holding torque, and `Ki = 0` never integrates that droop away. `arm-setup gains sweep`
(below) measured it on `elbow_flex`, stepped -0.200 rad from rest:

| Kp | steady error | reached | load (of 1000) | Kp x error | settle | ripple |
|----|---|---|---|---|---|---|
| 16 (as shipped) | 0.068 rad | 66.0% | 188 | 1.09 | 0.58 s | 0 |
| 32 | 0.031 rad | 84.4% | 168 | 1.00 | 0.50 s | 0 |
| **64 (applied)** | **0.014 rad** | **92.8%** | **144** | **0.92** | **0.46 s** | **0** |
| 128 | 0.008 rad | 95.9% | 144 | 1.06 | 0.46 s | 0 |

That is droop, **not** torque saturation: error falls 8.2x for an 8x gain rise
while load stays at 144-188, nowhere near the 1000 that saturation would pin it
to, and `Kp x error` holds within 1.18x. The servo was using about a fifth of
the effort available to it, so the 5.1-5.2 V supply was never the binding
constraint. A repeat run agreed to 1-2 encoder counts, and the same law holds on
a 1.0 rad step (0.038 -> 0.004 rad over the same gains) and at double speed.

**`Kp = 64` is applied** to all six servos and recorded in `robot.yaml`. It is
not the best-scoring gain — 128 measured better on every column, with no ripple,
no reversals and no overshoot at either step size or speed. It is chosen anyway,
because what the sweep tests is a *static hold on an unloaded arm*: a stiffer
loop reacts harder to a payload, a collision or hand-guiding, and none of those
are measured. 64 takes half the remaining error and keeps a measured 2x margin
below the highest gain that behaved. Revisit it with a payload on the gripper,
not from this table.

`Ki` stays 0. Swept at `Kp = 64`, integral action does close the gap —
`ki = 8` reached 99.7% of the step, error 0.001 rad — but settling stretched
from 0.46 s to 2.12 s as the integrator wound in, and `arm-pose` streams a fresh
setpoint every 50 ms, so nothing ever waits for that. It also stores the effort
used to hold a load, which is the lunge risk on unloading that made this a
deliberate test rather than a default.

With `Kp = 64` the full 3.19 rad (183 deg) `home` <-> `reachy` move completes in
both directions, lag steady at 0.05-0.08 rad, settling within **0.012-0.028 rad**
(0.7-1.6 deg) — against 0.026-0.041 rad at `Kp = 32`.

Gains live in servo EEPROM, so they are invisible config that a servo swap would
silently revert. `robot.yaml` is the source of truth and `pixi run arm-setup gains`
reconciles hardware with it:

```
pixi run arm-setup gains show     # read-only comparison against robot.yaml
pixi run arm-setup gains apply    # write and verify (asks first; EEPROM is persistent)
```

`apply` reports success only when a confirmed read-back matches, because an
EEPROM read-back races the relock: a single read taken too soon returns a
garbled value (observed: 250) and makes a successful write look failed. The bus
layer reads twice and trusts the value only when both agree.

### Measuring a gain instead of guessing it: `arm-setup gains sweep`

A gain is only defensible against a measurement, so the third subcommand takes
one and produces the evidence:

```
pixi run arm-setup gains sweep --joint elbow_flex --kp 16,32,64,128
pixi run arm-setup gains sweep --joint elbow_flex --kp 32 --ki 0,1,2   # the Ki question
```

It drives that one joint through the **same** step (`--step`, default -0.2 rad
from wherever the joint is resting) under each candidate gain set, sampling
position and load at 50 Hz, and scores each trial (`step_response.py`):

| Column | What it decides |
|---|---|
| `error` | how far short the joint settles — the droop itself |
| `kp*err` | constant across gains = proportional droop; not constant = something else |
| `load` | effort while holding, of 1000; near 1000 means torque saturation, not droop |
| `settle` | time to enter and stay in the settle band (2% of travel, min 2 counts) |
| `ripple`/`rev` | peak-to-peak motion and direction changes *while holding* — the counter-check on raising gain, since a hunting servo buzzes rather than holds |

It closes with a one-line verdict reading the sweep as droop or as saturation,
and writes every sample to `~/.mote/arm_gain_sweeps/<stamp>.json` so a run can be
re-read or plotted later rather than believed from a terminal.

Each trial writes its gains with torque **off** and then re-enables against the
joint's present position. Gains are EEPROM registers, and a servo that latched
them at torque-enable would run every trial at the same gain and report a droop
that mysteriously ignores `kp` — the sweep exists to stop us assuming that away.
The consequence is that the joint goes briefly limp between trials, so the arm
must be resting in a pose it holds unsupported (the same condition `arm_driver`
starts in).

The sweep moves the arm and writes EEPROM, so it is a bench tool with the
guards to match: it torques **only** the swept joint and leaves the rest limp,
refuses a step that would clamp against the soft limits (trials that command
different travel are not comparable), stops if the servo reaches `--max-temp`
(55 C default), and — via a `finally`, so a crash or Ctrl-C counts too — returns
the joint to where it started, writes the original gains back, and drops torque.
`test_gain_sweep.py` pins those properties against a simulated droopy servo, so
they are checked without hardware.

Closing the residual 1-3.5 deg would mean a small `Ki`, which is left alone for
now: integral windup on an arm risks a lunge when a load is removed, so it wants
a deliberate test on an unloaded joint first — that is what the `--ki` sweep
above is for. Supply voltage is worth revisiting only after that, since the arm
still has not demanded full torque.

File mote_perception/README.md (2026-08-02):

# mote_perception

Home for Mote's camera-derived perception nodes, built as staged layers:
**L0 (Foundation)** — package scaffold, camera health monitor, calibration
plumbing, compressed transport; **L1 (Obstacles)** — off-board monocular depth
feeding a Nav2 costmap layer; **L2 (Semantics)** — off-board open-vocabulary
detection feeding object poses to the task layer. This package **runs on the
robot** (it feeds Nav2), so unlike `mote_simulation` it is synced to the Pi.

## Nodes

- `camera_monitor` — subscribes to `image` (remapped to `/image_raw`) and logs
  the measured frame rate, resolution, and encoding every few seconds, warning
  when no frames arrive. Dependency-light (rclpy + sensor_msgs, no OpenCV).
- `depth_obstacle_node` — L1, see below.
- `object_detector_node` — L2, see below.

Run the launch:

```bash
pixi run perception
```

## Where things run

The depth (L1) and detection (L2) models are too heavy for the Pi, so each is a
**two-process split**: a light rclpy node and a torch inference server, talking
over a plain TCP socket (`depth_wire.py` / `detect_wire.py`). The split is by
concern, not by machine — which machine each half lands on is a deployment choice:

- **The nodes always run on the robot**, in its DDS graph, launched by
  `perception_launch.py`. Five of a node's six edges (image, camera_info, scan,
  tf, and its Nav2/task output) live in that graph; only inference leaves, over
  one TCP hop. Each node is torch-free and idles cheaply when its server is
  unreachable (throttled warnings; the detect node doesn't even pull the camera
  stream until it has labels), so it's safe to leave enabled without a server.
- **The inference servers run wherever the compute is** — `pixi run inference`
  starts both (depth + detect) in the torch-only `inference` pixi env. That's a
  GPU box, or the robot/dev machine itself. `pixi run inference-rocm` runs the
  same pair on an AMD ROCm GPU (the Linux-dev fallback tier; see the L1 section
  for the iGPU caveats). As a *deployed role* on a dedicated NVIDIA machine — a
  gaming PC or a cloud GPU — the same servers ship as a **container image**
  (`ghcr.io/clachdev/mote-inference`), so that host installs no repo, pixi, or
  scripts: see **[`docs/inference-server.md`](../docs/inference-server.md)**.
  Every variant runs the same supervisor (`tools/inference_server.py`).

The only knob is **`inference_host`** in `config/perception.yaml` (with the same
`$MOTE_HOME/perception.yaml` override as the camera calibration): leave it
`127.0.0.1` to run everything on one machine, or point it at the GPU box to
offload just inference. The same file's `depth.enabled` / `detect.enabled` toggle
each node — turn one off if the Pi can't carry its per-frame CPU cost. Nothing is
passed at launch time.

Check the server from the robot with **`pixi run inference-health [--host H]`**
(torch-free — prints each service's model/device/GPU/version, or `DOWN`), and
measure round-trip latency with **`pixi run inference-bench`** (see
[`benchmarks/`](benchmarks/README.md)). When the server is absent the nodes warn
and skip frames — nav keeps running on lidar alone; the full fallback matrix is
in the inference-server doc.

> Note: `perception_launch.py` is a separate process, not part of the mission
> bringup — run `pixi run perception` alongside `pixi run mapping`/`robot`.

## Camera calibration

A committed default calibration (`config/camera_info.default.yaml`) ships as a
fallback, and a per-robot `~/.mote/camera_calibration.yaml` overrides it when
present. Most robots need no calibration of their own — see
[`config/README.md`](config/README.md) for when it's worth doing and the
`camera_calibration cameracalibrator` procedure.

## Compressed transport

`ros-jazzy-image-transport-plugins` is already a project dependency, so the
camera node publishes `/image_raw/compressed` automatically alongside the raw
stream. Off-board consumers (RViz on a workstation, remote viewers) should prefer
the `compressed` transport — raw 640x480 @ 30 FPS is roughly 28 Mbps, which
saturates Wi-Fi.

Note: a `ros2 topic pub` of a fake `sensor_msgs/msg/Image` will **not** produce a
`/image_raw/compressed` topic. Only a real `image_transport` publisher (the
camera) or an `image_transport republish` node emits the compressed variant.

## L1 — Obstacle perception (off-board monocular depth)

Turns the single RGB camera into a `PointCloud2` of obstacles (`/camera_obstacles`)
for a Nav2 voxel/obstacle layer — catching the low/thin things the 2D lidar plane
misses (cables, thresholds, table & chair legs, a robot vacuum). The lidar stays
the primary, low-latency obstacle and clearing source; this is a slower
supplementary **marker**.

### Live output

On the robot, facing a cluttered floor:

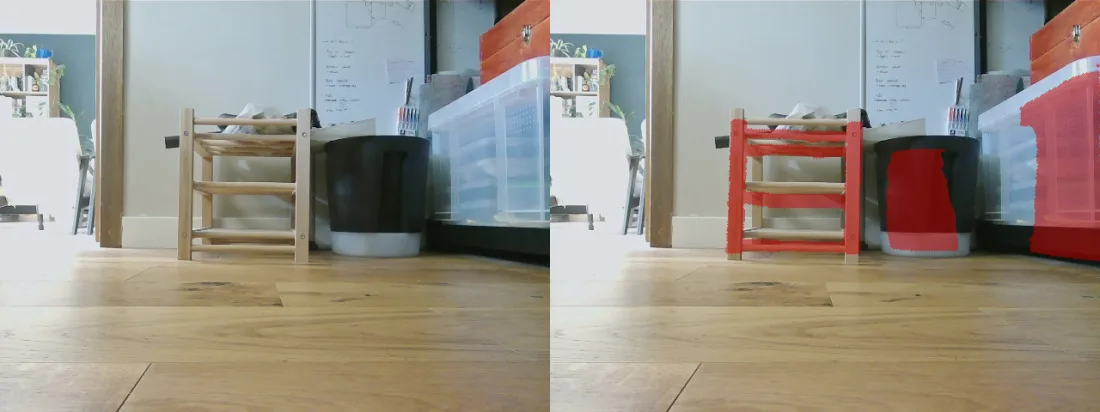
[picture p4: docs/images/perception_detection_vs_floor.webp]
Obstacle detection vs. a clean floor: stool legs, bin and a transparent box mark; the open floor stays clear.


*Detection (right) vs. raw camera (left): the stool legs, bin, and a **transparent** box mark — while the open floor produces no false positives.*

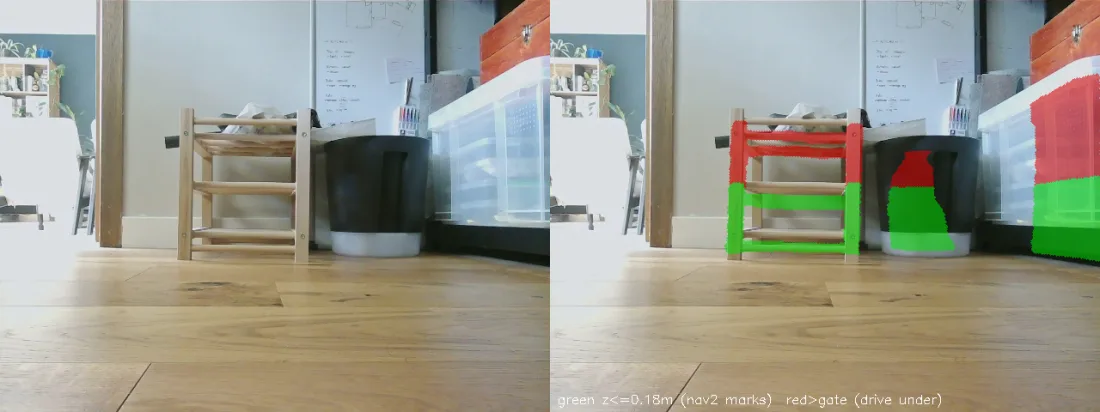
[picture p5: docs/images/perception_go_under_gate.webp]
Go-under height gate: green marks so Nav2 avoids; red is above the gate, passable overhead.


*Go-under gate: green (≤ 0.18 m) marks so Nav2 avoids the legs; red is above the robot's height and passable — it paths through the gap beneath a seat or tabletop.*

Pipeline: **Depth Anything V2-Small (relative)** gives a dense disparity map,
inverted to depth. Its scale is arbitrary, so every frame is **metrically rescaled
by an affine-in-disparity fit (Theil-Sen) anchored to lidar range returns**
(`lidar_rescale.py`) — the lidar gives metric truth through a chassis-fixed
transform that's invariant to body/floor tilt. When a scan can't constrain the
fit (facing a flat wall, no depth spread) the last good correction is held; before
the first fit the frame is skipped. (An earlier floor-plane scale anchor was
removed: it shifted with floor slope and resting pitch.) The floor plane is then
fit per frame and the cloud rotated level (`ground_projection.py`) to remove
residual camera tilt, so a point's z is its true height above the floor. Points
above `z_obstacle` (default 0.02 m) become the cloud, stamped at **image-capture
time** so Nav2 places it via tf at the moment it was seen (this is how the off-board
latency is absorbed).

Depth inference is too heavy for the Pi CPU (~0.5 s/frame), so it runs **off-board**.
The split is between the two processes, *not* between two machines — see
[Where things run](#where-things-run):

- `depth_obstacle_node` — light rclpy node (no torch); forwards each compressed
  frame to the server, rescales, and publishes the cloud. Runs **on the robot** in
  its DDS graph, launched by `perception_launch.py` next to the camera/lidar/tf it
  consumes and the Nav2 that consumes its output.
- `tools/depth_server.py` — keeps the model resident and serves depth over a
  socket, in the torch-only `inference` pixi env (kept out of the ROS/robot env on
  purpose). Runs wherever the GPU is; the node reaches it over TCP at
  `inference_host`.

`pixi run inference-rocm` runs the servers in the `inference-rocm` pixi env (torch
from the pytorch.org ROCm wheel index; see `pixi.toml`) so inference runs on an AMD
GPU. The server picks `cuda` when `torch.cuda.is_available()` else `cpu` — override
with `--device cpu|cuda`, and `--fp16` for half precision (GPU only). On an idle
workstation the iGPU is no faster than the CPU (this small ViT is
bandwidth-bound), but it stays flat under CPU load (RViz + ROS + the obstacle
node) where the CPU-only server degrades to ~1–2 s/frame, and it frees the CPU
for Nav2. It needs a working ROCm GPU: on an unsupported iGPU (e.g. gfx1103) the
env sets `HSA_OVERRIDE_GFX_VERSION=11.0.0` to masquerade as a supported target,
and the user must be able to open `/dev/kfd` (be in the `render`/`video` groups).
fp16 and larger models (V2-Base/Large) can crash or hang on unsupported iGPUs —
keep the default fp32 + V2-Small there.

The wire protocol between them (length-prefixed TCP frames) is defined in one
place, `mote_perception/depth_wire.py` — the spec, the framing helpers, the
`DepthClient` used by the node and the offline tools, and the reasons a
hand-rolled protocol beats gRPC/ROS for this link are all in its docstring.

Key params: `z_obstacle` (height deadband, default 0.02 m — below ~1.5 cm floor
noise false-positives), `range_min`/`range_max` (default 0.25–1.2 m: the mount's
usable floor band, past which monocular depth compresses into false positives),
`server_host`/`server_port`.

### Nav2 costmap layer

`camera_obstacles` feeds a dedicated `camera_layer` on the **local** costmap only
(`mote_bringup/config/nav2_params.yaml`) — near-band and reactive, so it can stop
the robot at a low obstacle without the phantom risk a slow, laggy source would add
to the global plan. It is a separate layer from the lidar `obstacle_layer`: the
lidar stays the primary marking/clearing source and the camera can never clear a
lidar mark (`combination_method: 1` takes the max of the two).

**Marks expire on a clock, not by raytracing.** The layer is a
`spatio_temporal_voxel_layer`, not Nav2's `VoxelLayer`, because this cloud carries
*only above-floor* points — the node strips the floor to keep the stream off the
Wi-Fi. A voxel layer clears only by raytracing towards a point in a later
observation, so a person who walks through the band and leaves takes their points
with them: nothing is ever observed in that direction again, no clearing ray
crosses the marks they left, and the marks are permanent. `clearing: True` on the
source was inert over open floor, and publishing floor points would only half-fix
it (rays from the 0.10 m camera descend, so the 0.10–0.18 m band still gets no
crossing). STVL instead expires a voxel `voxel_decay` seconds (5 s) after the last
time it was marked, whatever the viewing geometry — an obstacle still in view is
re-marked every frame and never expires, one that leaves goes on its own. The
number is a memory-vs-staleness trade: below ~2 s the robot forgets a low obstacle
while steering round it (the camera loses it below `range_min` 0.25 m, about a
second before the wheels reach it); 5 s is ~1 m of travel at the 0.218 m/s wheel
limit. Frustum clearing (`clearing: True` plus the FOV parameters) is deliberately
left off: decay already answers staleness, and a mis-stated FOV would clear real
obstacles the lidar plane cannot see. `sensor_frame: camera_optical_link` still
names the real camera (the cloud itself carries leveled `base_footprint`
coordinates), which is where that frustum would be anchored.

Two STVL settings are load-bearing rather than cosmetic. `clear_after_reading:
True` — the measurement buffer holds its newest cloud until something empties it
and every costmap update re-marks whatever it reads, which restamps the voxels with
the current time; without it a departed obstacle is refreshed at 5 Hz forever and
the decay never fires, reproducing the exact bug the layer was swapped in to fix.
And `filter: "passthrough"` — STVL applies `min_obstacle_height`/`max_obstacle_height`
*as that filter's z limits*, so `filter: "none"` would silently drop the go-under
gate below rather than just skipping downsampling.

**Go-under clearance.** The obstacle band has an upper bound so the robot isn't
blocked by things it fits beneath. The camera layer's `max_obstacle_height` is the
robot's height plus a margin: **0.18 m for the current ~0.13 m chassis (no arm)**.
A chair seat or tabletop above that is passable overhead and does not mark;
because it is a 3D voxel layer, the *legs* (which reach the floor) still mark, so
the robot avoids the legs and paths through the clear gap between them. **With the
planned arm the robot is ~0.30 m** — raise the gate to ~0.35 m; unlike `VoxelLayer`
there is no separate grid ceiling to raise alongside it. Note the go-under benefit
largely disappears at that height. The node mirrors the gate with a generous
`z_obstacle_max` publish ceiling (0.5 m — Nav2 is the authoritative gate) so it
doesn't stream points Nav2 discards; the node's `z_ceiling` bounds only the full
debug cloud.

Near-band false positives measured ≈ 0 on clean floor (including bright/specular
sun-glare floor, the case that defeated the classical spike), and a phantom that
does appear now expires with everything else after `voxel_decay`.

Live bring-up (the remaining gate — all validation so far is offline against
recorded bags): run `pixi run perception` on the Pi **alongside** `pixi run
robot`/`nav`, and `pixi run inference` on the inference machine (both on the Pi via
the default `inference_host: 127.0.0.1` if it can carry the CPU/GPU load). Then
check, in order:
1. `/camera_obstacles` is publishing (~2 Hz) and the `camera_layer` actually marks
   in the local costmap. If it doesn't, the off-board ~0.6 s latency is the first
   suspect — raise the local costmap `transform_tolerance` (the cloud is stamped at
   capture, so tf must still hold that stamp).
2. Drive slowly past a low obstacle (cable / threshold / the clothes-horse
   cross-bar) and confirm it marks and the controller avoids it.
3. Watch for motion-only false positives: `_ground_correct` holds the last good
   level rotation when a frame's floor fit fails, and a stale rotation applied at a
   new pose can tilt the floor above the 0.02 m gate. Static-frame evals can't
   surface this; if it appears, tighten `plane_max_tilt_deg` or the fit gates.
4. Stand in front of the stationary robot until you mark, then step out of shot
   and leave it still. The marks must go within ~5 s (`voxel_decay`) *without the
   robot moving*. If they persist, the buffer is being re-marked — check
   `clear_after_reading` survived whatever edited the layer.

## L2 — Semantic understanding (off-board open-vocabulary detection)

Turns "fetch the red box" into a map pose. OWLv2 detects arbitrary text queries
— no training, no fixed class list — so the fetch target is whatever the task
command names. Same two-process split as L1, with the query riding in each
request:

- `tools/detect_server.py` — keeps OWLv2 resident in the torch-only `inference`
  pixi env, serving detections over a socket (`pixi run detect-server`, or
  `pixi run inference` to run it beside the depth server; protocol in
  `mote_perception/detect_wire.py`). Picks `cuda` when available (override with
  `--device cpu|cuda`); on the CUDA inference PC it runs on the GPU, on CPU it
  uses all cores.
- `object_detector_node` — light rclpy node (no torch). Idles until a label set
  arrives on `detect/labels` (std_msgs/String, comma-separated, transient_local;
  empty string = idle) — the task layer's `AcquireObject` sets it while a
  mission needs a pose and clears it after. While idle the node holds **no
  image subscription at all**, so it costs neither inference nor a second copy
  of the camera stream over Wi-Fi. To drive it by hand (debug/demo), the
  publisher must match the transient_local durability or DDS silently drops
  the message:
  ```bash
  pixi run -- ros2 topic pub --once --qos-durability transient_local \
    /detect/labels std_msgs/msg/String "{data: 'shoe, cup'}"
  ```
  Each detection is **grounded by dropping the bbox bottom-centre pixel through
  the floor plane** (`GroundProjector.pixels_to_ground`) — the fetch mission's
  objects sit on the floor, so no depth model is needed in this loop — then
  transformed to the map frame **at the image capture stamp**, absorbing the
  off-board latency the same way L1 does. Poses go out on `detected_objects`
  (vision_msgs/Detection3DArray, map frame); `detections` (2D boxes) and
  `detections/overlay/compressed` (annotated JPEG) serve debugging/RViz.
- The node runs with the rest of perception (`pixi run perception`); its OWLv2
  server runs with `pixi run inference` (or `pixi run detect-server` alone).
  Against the sim, first bridge the raw camera into the compressed transport
  the node consumes (the robot's camera publishes it natively; the gz bridge
  does not):
  ```bash
  pixi run -- ros2 run image_transport republish raw compressed \
    --ros-args -r in:=/image_raw -r out/compressed:=/image_raw/compressed -p use_sim_time:=true
  ```

Grounding accuracy note: with the camera at ~0.10 m the floor rays are shallow,
so range error grows quickly with distance — metre-scale beyond ~2 m. That is
fine for its job (navigate *towards* the object; the goal is a standoff pose,
not a grasp), and `range_max` (default 3.0 m) drops anything farther. Key
params: `min_score` (default 0.3; the server's `--threshold` stays low so score
policy lives client-side), `range_max`, `server_host`/`server_port`.

### Offline tools

Everything is developed and validated offline against recorded bags
(`pixi run record`). All run in the dev/default env; the three depth tools need a
server up (`pixi run depth-server`). Shared bag loading lives in
`tools/bag_utils.py`; each tool's docstring has the details.

- `depth_bag_replay.py` — re-runs the exact pipeline on a bag; prints per-frame
  fit diagnostics (the rig that found the RANSAC bistability).
- `depth_bag_eval.py` — model accuracy/speed vs lidar, plus side/BEV inspection
  views; model-agnostic, for comparing depth servers.
- `depth_obstacles.py` — decision-level overlay (what marks and why) and the
  camera-vs-lidar BEV, both point sets transformed into `base_footprint`.
- `detect_bag.py` — L2 sanity harness: open-vocab detection over a bag's frames,
  writing overlays with boxes, scores, and grounded floor positions (needs
  `pixi run detect-server`).
- `bag_overlay.py` — geometry sanity check: floor grid + lidar projected into
  the camera frames.
- `measure_camera_pitch.py` — live checkerboard measurement of camera
  pitch/roll/height (mount calibration).
- `sfm_stage0_geometry.py` — multi-view depth feasibility harness (issue #21,
  Stage 0): parallax across the image, pose-at-stamp accuracy, and usable-baseline
  duty cycle from a bag's `/tf` + images alone (no server, no lidar). Findings in
  [`design/research/sfm_stage0_results.md`](../design/research/sfm_stage0_results.md).

### Inference-server tools

Run the servers and operate them from the robot side. See
[`docs/inference-server.md`](../docs/inference-server.md) for the deployment
role and [`benchmarks/`](benchmarks/README.md) for numbers.

- `tools/inference_server.py` — cross-platform supervisor that runs every service
  (the `SERVICES` list) bound to `0.0.0.0` and tears the rest down if one dies; the
  `inference` / `inference-rocm` tasks and the container entrypoint all run it. Add a tenant
  by adding a row.
- `tools/inference_health.py` (`pixi run inference-health`) — torch-free probe of
  each service's health/version over the wire; `DOWN` if unreachable, non-zero exit
  if any service is down.
- `tools/inference_bench.py` (`pixi run inference-bench`) — torch-free round-trip
  latency/fps benchmark against a server; writes JSON for the benchmarks dir.
- `tools/prefetch_models.py` (`pixi run inference-prefetch[-cuda|-rocm]`) — warm the
  HuggingFace cache so the first request doesn't block on a download.
- `tools/model_host.py` — on-demand model loading: the servers load on the first
  request and release the model (and its VRAM) after `--idle-timeout` seconds
  idle, so the inference machine stays usable as a normal PC between missions.
- `tools/probe.py` — the deployment's gate, and the one tool that lives *inside*
  the image: health **plus a real synthetic frame** through each service, so a
  build that listens but cannot infer fails it. `inference-health` is its
  robot-side sibling (same sentinel, but it resolves `inference_host` from
  `perception.yaml` and needs yaml, which the image does not carry).
- `deploy/Dockerfile` — the inference-server image (depth + detect, CUDA torch,
  model weights baked in), built and pushed to GHCR by
  `.github/workflows/inference-image.yml`. The host runs one `docker run`; it
  never needs the repo. Servers report the image's baked `MOTE_VERSION` in the
  health blob, so `inference-health` warns on robot/server version skew.
- `deploy/inference-deploy.sh` — the update pipeline: probe a candidate on shadow
  ports while the current version keeps serving, cut over, roll back if the live
  probe fails. One file on the host, no repo. See
  [`docs/fleet/server-pipelines.md`](../docs/fleet/server-pipelines.md).
- `deploy/test/` (`pixi run deploy-test`) — that pipeline exercised end to end
  with stub images that speak the real wire protocol: four checks, a minute, no
  GPU, on any machine with docker.

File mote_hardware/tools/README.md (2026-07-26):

# mote_hardware tools

Dev tools built alongside the hardware package. All use the SCServo SDK directly,
bypassing ros2_control. Run with `ros2 run mote_hardware <tool>`.

## setup_ids

Guided first-time servo ID assignment. Sets the wheel IDs Mote expects:
left = 7, right = 9 (matching LeKiwi). Fresh STS3215 servos all ship as ID 1, so
they can't be told apart on a shared bus — this tool configures them one at a
time, detecting whichever single ID is on the bus and reassigning it.

```
ros2 run mote_hardware setup_ids [port] [baud]
```

Connect only the left servo when prompted, then only the right. Safe to re-run
(it handles servos already at 7 or 9). Use `swap_ids` instead if both IDs are
already set but the wheels drive the wrong way round.

## servo_debug

Interactive REPL for driving and inspecting individual servos. Useful for
checking wiring, servo IDs, and direction conventions.

```
ros2 run mote_hardware servo_debug [port] [baud]
```

Commands: `mv <id> <speed>`, `stop <id>`, `stopall`, `r <id>`, `m <id> [hz]`,
`ping <lo> <hi>`. Type `help` for the full list.

## servo_ping

Non-interactive counterpart of `servo_debug`'s `ping` — pings a fixed set of
servo IDs and exits `0` if every one responded, `1` otherwise. Used by the
startup self-check (`mote_bringup` `self_check.py`) to gate bringup on the drive
servos actually answering. Run the bus free (before bringup opens it).

```
ros2 run mote_hardware servo_ping [port] [baud] [id ...]
```

Defaults: `/dev/mote_servos 1000000`, IDs `7 9` (the drive IDs in `robot.yaml`).

## velocity_cal

Measures `velocity_scale` (the rad/s → raw servo units conversion factor) by
commanding a series of speeds and computing actual angular velocity from encoder
ticks. Lift the robot before running so the wheels spin freely.

```
ros2 run mote_hardware velocity_cal [servo_id] [port] [baud]
```

Outputs a recommended `velocity_scale` value. Update it in:
- `mote_description/urdf/mote.urdf.xacro`
- `mote_bringup/launch/mote_launch.py`

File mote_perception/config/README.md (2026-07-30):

# Camera calibration

The camera intrinsics tell ROS the lens geometry so it can undistort images and
project pixels to rays. Mote resolves them at launch with a fallback:

1. **`~/.mote/camera_calibration.yaml`** — this robot's own calibration, if it
   exists. Per-robot and intentionally **outside the repo**.
2. **`camera_info.default.yaml`** (this directory) — a representative default for
   the UGREEN webcam, committed so a fresh checkout / new robot works out of the
   box.

`mote_launch.py` uses the `~/.mote` file when present, otherwise the packaged
default (`robot.yaml`'s `camera.default_info_url`).

## Do you need to calibrate?

Usually **no** — intrinsics barely vary between identical camera units, so the
committed default is fine for display and coarse perception. Calibrate your own
(and save it to `~/.mote/camera_calibration.yaml`) when:

- you fitted a **different camera** than the UGREEN model the default was made for;
- you need **metric accuracy** — e.g. the L1 obstacle/depth work that projects
  pixels onto the ground or into 3D, where small intrinsic errors bias range;
- straight edges look **curved** in the rectified image, or `/camera_info`
  clearly doesn't match your lens;
- you changed the capture **resolution** (the default is for 640x480).

## Print the target

Print [`checkerboard_a4_25mm_7x10.pdf`](checkerboard_a4_25mm_7x10.pdf) on A4 — it
is **7x10 squares of 25 mm** (so **6x9 inner corners**), with the calibrator
parameters printed along the bottom edge.

The page is deliberately a little smaller than A4 so it fits inside the printable
area of any A4 printer: most printers should print it unscaled, and the squares
come out true-size **without changing any print settings**. Just print it on A4
and the board is centred with a white border.

- **Mount it dead flat** on a clipboard, foamboard, or glass. A floppy sheet
  warps and wrecks the result.
- The squares should measure 25 mm on each side however if they do not match
  exactly it should still calibrate correctly. The **intrinsics** are
  independent of the absolute square size — square size only affects metric
  scale, which this calibration does not rely on.

## Running the calibration

`cameracalibrator` is an interactive GUI tool, so run it on the **workstation**
(it is a `dev` dependency, not installed on the robot) against the Pi's live
camera over the ROS 2 network. Both machines must be on the same LAN and
`ROS_DOMAIN_ID`.

This is the one flow that joins the robot's graph over the LAN: DDS transport
is loopback-only by default everywhere (`mote_bringup/config/cyclonedds.xml`,
via `CYCLONEDDS_URI`), so both ends must drop that profile for the session.
The `camera_calibration` task does it itself; anything started by hand on the
Pi needs the `env -u CYCLONEDDS_URI` prefix shown below.

1. Print and mount the target above.
2. On the **Pi**, start the camera so it publishes `/image_raw` on the LAN —
   not under the loopback profile, so not `pixi run launch`; run the camera
   node alone:

   ```bash
   pixi run -- env -u CYCLONEDDS_URI ros2 run v4l2_camera v4l2_camera_node \
       --ros-args -p video_device:=/dev/mote_camera
   ```
3. On the **workstation** run the calibrator:

   ```bash
   pixi run camera_calibration
   ```

4. Move the board through the frame until the X/Y/Size/Skew bars are full, then
   press **CALIBRATE**. It prints the result (`camera matrix`, `distortion`,
   `rectification`, `projection`) to the console in oST format.

   Copy the printed parameters into a `camera_calibration.yaml` file.

5. **Install it.** Copy calibration file to `~/.mote/camera_calibration.yaml`
  **on the Pi**.

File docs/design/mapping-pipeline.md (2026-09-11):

# The mapping pipeline

How a space becomes a promoted map: **mapping as a build process** — the bag is
the source, the map revision is a build artifact, the parameters are the
toolchain, and promotion is a release. The robot's live map is scaffolding for
navigation during capture and is never the deliverable.

This is a design document. No implementation lands with it; the work breakdown
at the end is sized so each item becomes one dispatchable task.

> **Scope note.** This builds on seams that already exist: the site bundle and
> its validator (`mote_bringup/mote_bringup/sites.py`,
> `mote_bringup/mote_bringup/bundle.py`), the map registry and its promotion
> flow (`docs/design/fleet.md` M4, `mote_fleet/server/bundle_store.py`), the
> zone vocabulary (`GET /v1/zones` serves the names — fleet-api.md), the
> declutter/segmentation passes (`mote_bringup/mote_bringup/map_cleanup/`), and
> the lockstep replay harness (task 295, `mote_simulation/tools/bag_replay/`).
> None of those move. What this design changes is **what happens between them,
> on which machine, and under whose control**.

---

## Evidence: the 2026-08-02 flat-mapping session

Every step below happened by hand, in a session that produced the best map this
project has had. That is the smell: the good outcome required leaving the paved
road at nearly every stage.

- The live session tore itself (a stuck-escape at a doorway injected drift) and
  the live config could not recover: `loop_match_minimum_chain_size: 15` needs
  a ~4.5 m chain of prior scans inside a 2.0 m search radius whose chord holds
  at most ~13 — closure candidates **cannot form**, at any drift. The saved
  live map (`home/ground/20260802T145731`) was discarded as an artifact and
  kept only as a baseline.
- The map that shipped was built **offline from the bag**: lockstep re-solve
  under corrected params (21 s per leg against ~35 min paced — the economics
  that make this whole design viable), a measured-then-injected frame rotation
  to square the walls (two solves, at a build-only 1° `coarse_angle_resolution`
  on the reasoning that the live 2.0° value snapped solutions to a ~2°
  orientation lattice — **there is no such lattice**, and the finer sweep beat
  the live value on nothing; see the alignment step below), a declutter pass
  with a hand-tuned peak threshold (the default admitted a phantom wall
  direction — task 337), room segmentation, and validation.
- Getting the artifact onto the robot and into the registry required
  hand-assembly of a revision (the layout `save-map` writes, reproduced
  manually), an rsync side-load, a manual symlink flip, and a `publish-map`
  whose design assumes the robot built the map. Distribution order ran
  backwards (robot first, registry second).
- Zones: `segment-map` proposed seven placeholder rooms; renaming is manual;
  the one taught pose (`office`) was invalidated by the new frame and had to
  be captured again (the dashboard's zone editor, which can now place it on the
  candidate, did not yet exist). The candidate was published with placeholder
  names because packing happens at publish time.
- The bags themselves — the actual source — live in the robot's
  `~/.mote/bags/` under a pruner that trims older bags on every recording run.
  Three weeks of mapping bags existed only there until they were pulled by
  hand this session.

Total: one excellent map, roughly a dozen manual judgment calls, and a paved
road that covers none of it.

## Principle

**Capture produces a bag. A build produces a map. A human review promotes it.**

- The **bag** is the product of driving the space. It is synced off the robot
  automatically, retained deliberately, and is sufficient to rebuild every
  downstream artifact from scratch.
- The **map revision** is a deterministic function of (bag, build params,
  harness version). Rebuilds are cheap (~seconds), so the build can afford
  steps a live session cannot: aggressive loop closure, alignment iteration,
  quality scoring against the previous revision.
- The **live map** exists so the robot can navigate while capturing. Its
  params are the best known-good configuration — never deliberately hobbled
  gates (a closure setting that cannot fire is a bug, not a tuning) — but it is
  held to a lower bar than the deliverable: a drifted live map degrades
  frontier exploration, not the product.
- **Live and build params may diverge, deliberately.** A false closure live is
  unrecoverable mid-mission; offline it costs one inspected, discarded
  candidate. So the live config carries conservative, proven values, and the
  build config may optimise further — every build output passes scoring and a
  human eye before release. The two configs live side by side in
  `mote_bringup/config/` with the divergence documented per key.

## The pipeline

Three machines, four stages, one direction of data flow:

```
 robot (Pi)              fleet box                     operator (browser)
 ───────────             ─────────────────────────     ──────────────────
 1 CAPTURE  ──bag──▶     2 BUILD   ──candidate──▶      3 REVIEW ──promote──▶  4 DISTRIBUTE
   drive + live SLAM       solve/align/clean/            see map + zones,       registry flips,
   (nav scaffolding)       segment/carry-forward/        edit zones,            retained announce,
                           validate/score                approve                robots pull
```

### Stage 1 — Capture (robot)

What runs: `pixi run mapping` + `pixi run explore` (or teleop assist), exactly
as today. The live SLAM stack navigates; the `mapping` bag stream records
`/scan_filtered`, `/tf`, odometry context.

What changes:

- **Bags sync off the robot automatically** when a mapping session ends (and
  opportunistically during long sessions): robot → fleet box, verified by
  checksum, into a bag store beside the map registry. The robot-side pruner
  may only trim bags the fleet box has confirmed — sync-then-prune, never
  prune-then-hope. (2026-08-02: 8 mapping bags existed only on the Pi, one
  recording run away from deletion.)
- **`save-map` stops being the deliverable path.** It remains as a
  bench/sim convenience (`map_world.sh` still uses it), but the operator flow
  never calls it: ending the session is enough.

Controls: session start/stop is the only operator input. The robot uploads
bags under its enrolled identity; it can no longer be the only holder of a
mapping session.

### Stage 2 — Build (fleet box)

Trigger: a new bag arriving, or an operator asking for a rebuild of an old bag
under new params. One orchestrator (`pixi run map-build <bag>`) chains what was
done by hand on 2026-08-02:

1. **Solve** — lockstep replay of the whole bag under the committed *build*
   params (`slam_toolbox_build_params.yaml`: the live file plus documented
   divergences, each one measured). Today that is one key,
   `loop_match_minimum_chain_size`, and only until the live file catches up:
   the live config is best-known-good by policy, so there is little for a build
   to win by parameter alone. What the build buys is the *steps* below.
   (`docs/tuning/2026-08-25-slam-build-params.md`.)
2. **Align** — measure the solved map's dominant wall orientation, re-solve
   once with that yaw injected as the frame birth-alignment, then **measure
   again and gate on the change**: the second solve must be at least as close
   to axis as the first, by more than the estimator's own resolution. It is a
   gate on improvement, not on absence, and the reason is that a map has no
   absolute residual to assert — on the 2026-08-02 flat, thirds of the building
   disagree about where the wall grid is by 8°, and there is a second family
   18° off that. Re-measuring is not belt-and-braces either: a re-solve is
   **not a rigid rotation** (slam_toolbox's correlation grid is a pixel grid,
   so a frame born 3° elsewhere finds different matches), and the same −3.0°
   injection moved three solves of one bag by +0.1°, −4.3° and −5.8°. The leg
   that did not move is the live-parameter one, i.e. the case the build will
   actually run.
   **This step is blocked on a measurement that does not exist yet** (work item
   10). `angular_stats.wall_rotation`, which the earlier draft of this design
   named, reports all seven banked 2026-08-02 solves as within 0.3° of square
   when four of them are 3.5–5.6° off, and mis-reads a known rotation below 2°
   by up to 0.75°. A projection-sharpness sweep over the same pixels finds the
   grid and holds a known rotation to 0.035° — but it is a throwaway probe, not
   a primitive. The before/after orientations and the tile spread ride on the
   candidate as review evidence either way. Evidence:
   `docs/tuning/2026-09-01-alignment-residual.md`.
3. **Declutter** — the FFT structure pass with prominence-based peak picking
   (task 337); no hand thresholds.
4. **Segment** — room polygons from the cleaned map, as today.
5. **Carry forward the names** — the previous revision's zone names, notes
   and poses re-bind onto the new geometry: same-frame rebuilds by containment
   (a named zone whose pose lands inside a proposed room claims it); a new
   frame gets proposed matches for the operator to confirm in review.
   Placeholder names are minted only for genuinely new rooms.
6. **Validate + score** — `bundle.validate`, then the truth-free metrics
   (loop drift when the trajectory closes, explored area, speckle, wall
   thickness) diffed against the current canonical revision. Regressions
   don't block — they are printed on the candidate for the reviewer.
7. **Package + upload** — assemble the revision (map, raw, yamls, posegraph,
   meta with full provenance: bag id, params hash, harness commit) and upload
   it to the registry as a candidate under a **build identity** (today's
   registry accepts uploads only from enrolled robots; the builder needs the
   same standing — this is the M7 credential shape arriving early).

Controls: build params are committed and versioned; every candidate's meta
names its exact inputs, so any candidate is reproducible; a failed gate stops
the candidate, a soft regression rides along as review evidence. Nothing in
this stage touches a robot or the canonical map.

### Stage 3 — Review (operator, dashboard)

The operator decision point, and the place the 2026-08-02 session had nothing.
Requirements, in priority order:

- **See the candidate.** Selecting a candidate in the promote picker renders
  *that revision's* map in the pane (route for a candidate's `map.png`; task
  339), clearly marked as a preview, with a one-click return to canonical.
- **See the zones on it.** The candidate's zones draw over the preview exactly
  as canonical zones draw today (circle, polygon, waypoint cross), plus the
  carry-forward report: which names re-bound automatically, which are proposed
  matches, which rooms are new placeholders.
- **Edit before promoting.** *Built* (task 339's review pane,
  `server/ui/zone_editor.mjs`): rename a zone, write its note, adjust or delete
  a polygon, and place a pose by clicking the map (`⌖`), which is what replaced
  driving to a goto target — `save-zone` remains for poses that need a real
  approach heading. A save derives a new candidate from the one under review
  rather than writing into it (bumping the floor's `revision`); the source's
  bytes never change and the result stays inert until promoted. Still to do:
  accepting or rejecting a proposed carry-forward match.
- **See the build report.** The scoring diff from stage 2, on the same page
  as the promote button.
- **Promote.** Unchanged M4 semantics: audited operator action, symlink flip,
  retained announcement.

The browser's write surface grows from one audited POST (dispatch) to three
(dispatch, zone edits on a candidate, promote) — all operator-token
authenticated, all audited, all inert until promotion except promotion itself.

### Stage 4 — Distribute (unchanged)

M4 as built: retained announcement, agents pull and verify, effect at next
bringup, zones travel inside the revision. The 2026-08-02 session bypassed
this stage (side-load first, registry second); with stages 1–3 in place there
is no reason to ever bypass it again, and the robot-side `site use-map` /
rsync path is demoted to a bench tool.

## What stays, what changes, what is new

| | |
|---|---|
| **Stays** | Site bundle layout + `bundle.validate` both ends; M4 registry, promotion, announcement, pull; zone vocabulary split; live-mapping stack for capture; lockstep harness |
| **Changes** | Live SLAM params become best-known-good (chain 15 → 10 now — task 335 — and whatever proves out next); `save-map`/`publish-map` demoted to bench tools; promote picker becomes a review surface |
| **New** | Bag sync + retention (sync-then-prune); build orchestrator + committed build params; an orientation estimator the alignment step can be gated on; build identity for candidate upload; vocabulary carry-forward; candidate preview/edit UI; build report |

## Decisions

- **The live config is never deliberately hobbled.** Best-known-good values,
  always; "strict to the point of unreachable" was a bug wearing a tuning's
  clothes. (Operator decision, 2026-08-02.)
- **Optimisation beyond known-good happens in the build**, where output is
  scored and reviewed before it can affect a robot.
- **The operator sees and edits what they promote.** No promotion on faith in
  a timestamp. (Operator decision, 2026-08-02.)
- **The bag store is the system of record for mapping sessions**; the robot is
  never the sole holder of one.
- **Zones' human half survives rebuilds.** Renaming a flat's rooms is done
  once, not per revision.
- **A build gates on what it can measure, and reports the rest.** Every gate
  names a threshold its own measurement resolves, demonstrated on a real map
  rather than a synthetic one; anything softer than that is review evidence
  printed on the candidate. An assertion the measurement cannot see is worse
  than no assertion, because it is believed. (2026-09-01, from the alignment
  step: a "< 0.5° residual" gate would have passed a map 3.6° out.)

## Open questions

- **Cross-frame rebinding confidence** — matching rooms between unrelated map
  frames (shape/adjacency) is heuristic; how much do we trust auto-matches vs
  always proposing? Start: always propose, never auto-accept across frames.
- **Bag retention** — how long does the fleet box keep bags? (They are the
  source; disk is cheap; start with "forever, compressed", revisit at fleet
  scale.)
- **Build triggers** — auto-build on bag arrival vs operator-initiated. Start
  operator-initiated; auto later.
- **Map pixel edits** — erasing a phantom wall, closing a door the lidar saw
  open. Out of scope here; zones-only editing keeps the review surface small.
  A future task can add a mask layer that survives rebuilds the way names do.
- **Buildings with no single wall grid** — the 2026-08-02 flat has an angled
  wing 18° off its dominant family, and even within that family its thirds
  spread 8°. Aligning such a map squares some of it and turns the rest. Does
  the build say so on the candidate and leave it to the reviewer, or is a
  spread past some width a reason not to align at all? Start: align on the
  dominant family and print the spread. `room_segmentation` has the same
  assumption and the same answer.
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

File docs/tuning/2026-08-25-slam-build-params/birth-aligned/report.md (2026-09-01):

# Bag-replay scoring report

- **generated (UTC):** 20260825T101353Z
- **git commit:** `ae37014`
- **bag:** `/home/michael/Projects/data/mote-bags/20260802_142539`
- **mode:** slam  ·  **feed:** lockstep
- **parameter sets:** 4

## Metrics

Truth-free proxies — see Limitations. Arrows mark the better direction.

| metric | car-0.0349 | car-0.0175 | car-0.01745 | car-0.01745-repeat |
| --- | --- | --- | --- | --- |
| scans replayed | 542 | 542 | 542 | 542 |
| pose-graph nodes | 340 | 340 | 340 | 340 |
| replay wall (s) | 21 | 21 | 21 | 21 |
| traj samples | 340 | 340 | 340 | 340 |
| path length (m) | 139.61 | 139.66 | 139.77 | 139.77 |
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

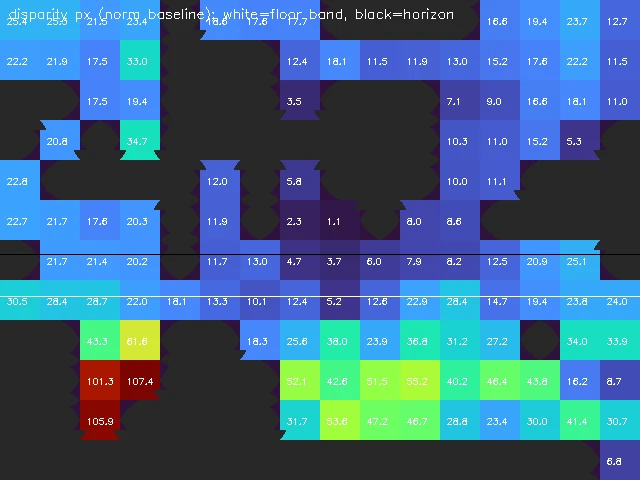
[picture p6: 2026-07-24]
design/research/sfm_stage0/parallax_heatmap.webp

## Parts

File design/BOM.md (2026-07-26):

# Bill of Materials

Prices in GBP. Sensor configuration add-ons are listed separately — the base
build uses a single USB camera.

## Base Build

### Structure

| Part | Qty | Unit price | Link |
| --- | --- | --- | --- |
| Chassis plates (3D printed) | — | (filament only) | — |
| M3 button head hex socket screw set (751pcs, M3×6–35, nuts, washers) | 1 | ~£6 | [Amazon UK](https://www.amazon.co.uk/dp/B0DSDJCRNB) |

### Electronics

| Part | Qty | Unit price | Link |
| --- | --- | --- | --- |
| Raspberry Pi 5 (4GB) | 1 | ~£99 | [CPC Farnell](https://cpc.farnell.com/raspberry-pi/rpi5-4gb-single/raspberry-pi-5-4gb/dp/SC20210) |
| Raspberry Pi 5 Active Cooler | 1 | ~£4.80 | [The Pi Hut](https://thepihut.com/products/active-cooler-for-raspberry-pi-5) |
| Waveshare Serial Bus Servo Driver Board | 1 | ~£15 | [Amazon UK](https://www.amazon.co.uk/dp/B0CJ6TP3TP) |
| Feetech STS3215 7.4V servo — 1/191 gear (C044) | 2 | ~£12 | [Alibaba](https://www.alibaba.com/product-detail/Low-Cost-Feetech-STS3215-Servo-7_1601611431055.html) |
| UGREEN Nexode 140W Power Bank 25000mAh, 2× USB-C (160×81×27mm) | 1 | ~£50 | [Amazon UK](https://www.amazon.co.uk/dp/B0BJQ7F16T) |
| USB cables (1× A to C 0.3m, 1× C to C 0.15m, 1× C to C 0.3m) | — | ~£5 | [AliExpress](https://www.aliexpress.com/item/1005008756186185.html) |
| USB-C to DC 5.5×2.1mm barrel cable (5V) | 1 | ~£2 | [AliExpress](https://www.aliexpress.com/item/1005007387571379.html) |
| SanDisk Extreme 64GB microSD (UHS-I, V30, A2, C10, U3) | 1 | ~£20 | [Amazon UK](https://www.amazon.co.uk/dp/B09X7C7LL1) | A2 rating is the key spec for Pi 5 performance |

### Sensors (base config)

| Part | Qty | Unit price | Link |
| --- | --- | --- | --- |
| UGREEN 1080p/30fps USB Webcam 85° FOV | 1 | ~£15 | [Amazon UK](https://www.amazon.co.uk/dp/B0C76ZD7KV) |
| SLAMTEC RPLIDAR C1 360° DTOF, 10Hz, 12m | 1 | ~£56 | [AliExpress](https://www.aliexpress.com/item/1005006641728089.html) |

**Base total (excluding print cost): ~£297**

---

## SO-101 Follower Arm

The chassis is compatible with the [SO-101 follower
arm](https://github.com/TheRobotStudio/SO-ARM100). Refer to that project for its
BOM and assembly instructions.

---

## In Testing

Parts not yet confirmed working on Mote — may be added to the base build or
optional extras once validated.

| Part | Qty | Unit price | Link | Notes |
| --- | --- | --- | --- | --- |
| BNO085 9-DOF IMU breakout | 1 | ~£15 | [AliExpress](https://www.aliexpress.com/item/1005010674706575.html) | Requires soldering iron to attach header pins. Intended for wheel slip detection and improved odometry when fused with wheel encoders via `robot_localization`. |

---

## Notes

- Sensor config slots on the chassis follow the ORP 3.5mm / 20mm grid standard.

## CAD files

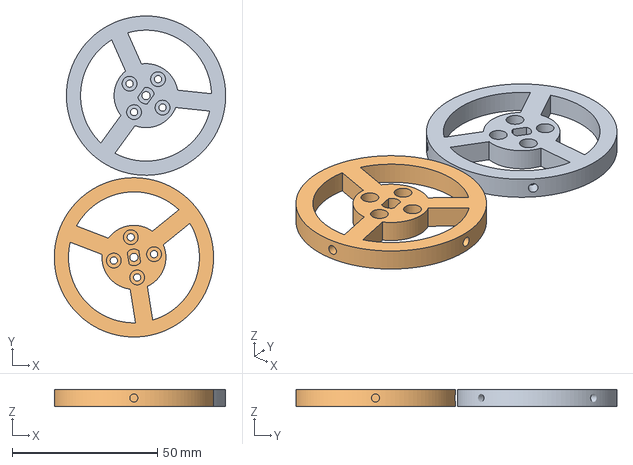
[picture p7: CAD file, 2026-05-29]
design/3mf/Wheel Inner.3mf
58.9 x 110.3 x 6.00 mm
WheelInner.stl x 2

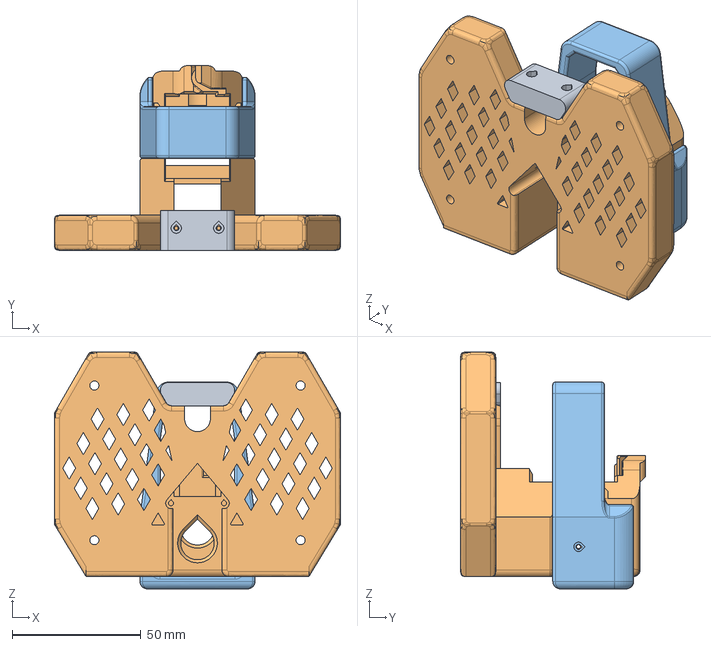
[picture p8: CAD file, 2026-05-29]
design/step/SO Base ORP.step
110.9 x 71.6 x 91.8 mm

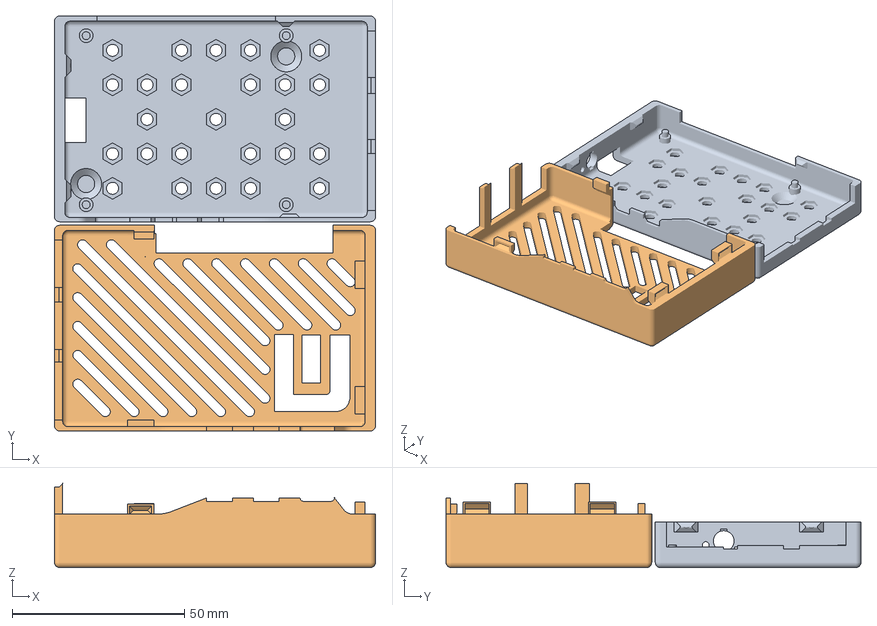
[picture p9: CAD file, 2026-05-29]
design/3mf/Pi Holder.3mf
93.1 x 120.3 x 24.4 mm
Pi Bottom.stl
Pi Top.stl

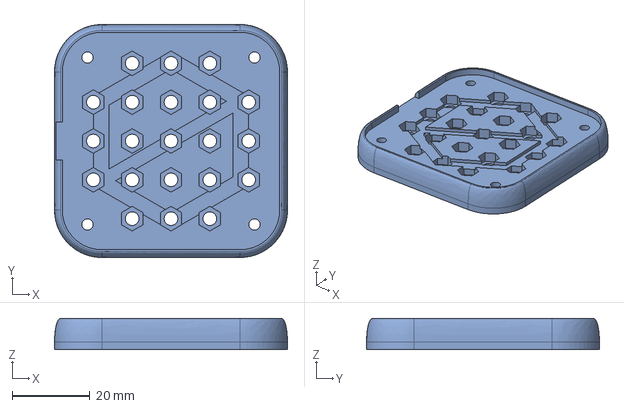
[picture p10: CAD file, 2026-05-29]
design/step/C1 Lidar Mount.step
60.0 x 60.0 x 8.00 mm

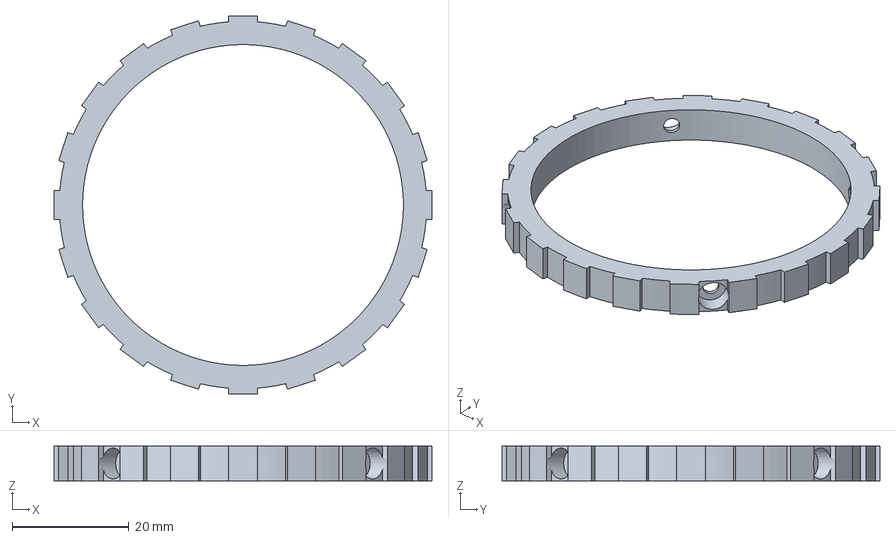
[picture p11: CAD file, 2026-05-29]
design/3mf/Wheel Tyre.3mf
64.8 x 64.8 x 6.00 mm

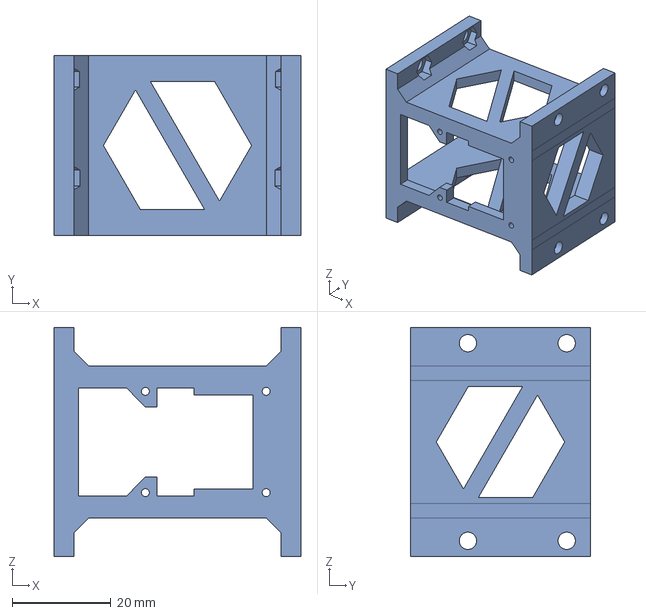
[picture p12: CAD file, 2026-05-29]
design/step/Motor Support.step
50.0 x 36.5 x 46.4 mm

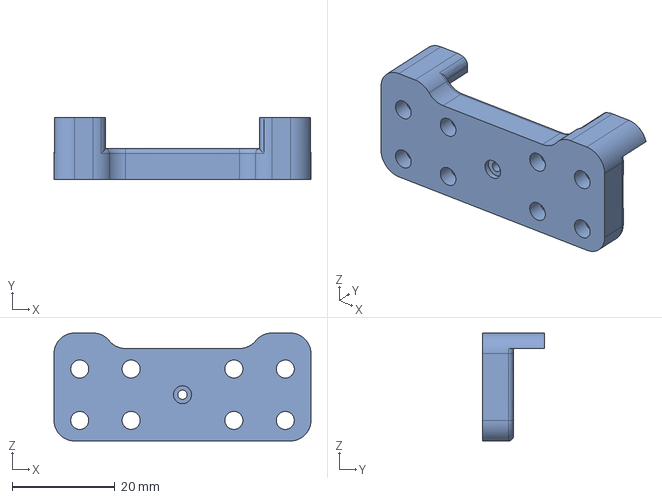
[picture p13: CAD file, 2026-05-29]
design/step/Camera Mount.step
50.0 x 12.0 x 21.0 mm

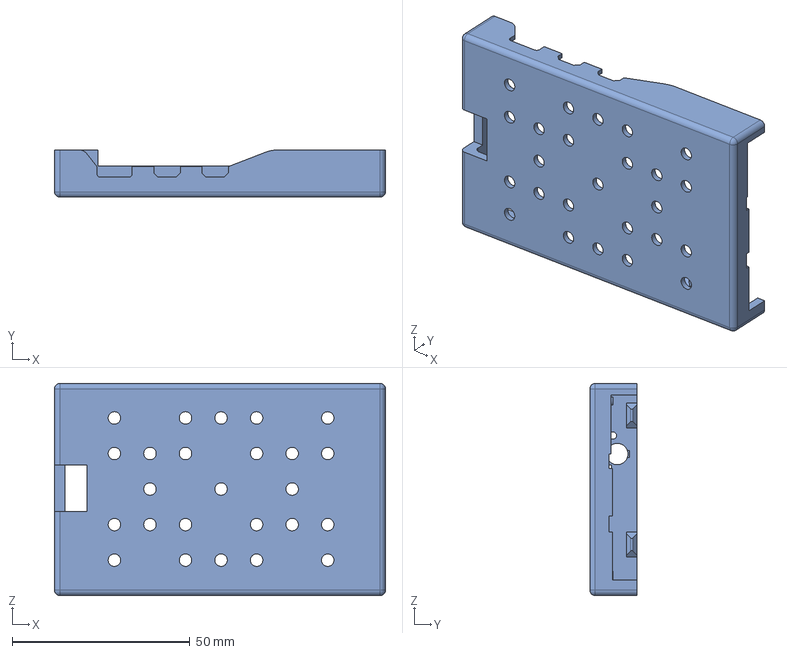
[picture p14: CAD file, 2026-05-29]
design/step/Pi Bottom.step
93.1 x 13.3 x 59.7 mm

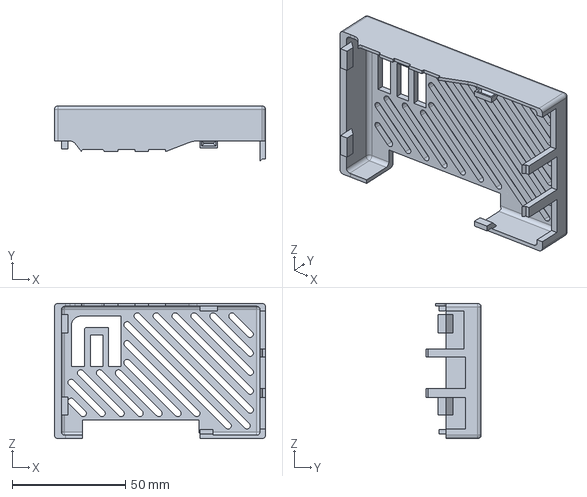
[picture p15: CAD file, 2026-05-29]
design/step/Pi Top.step
93.1 x 24.4 x 59.7 mm

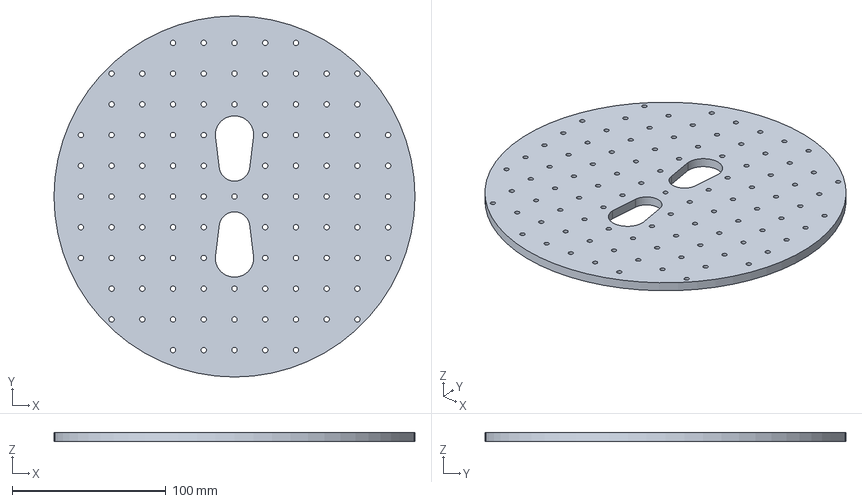
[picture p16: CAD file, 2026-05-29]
design/step/Chassis Top.step
235.0 x 235.0 x 6.00 mm

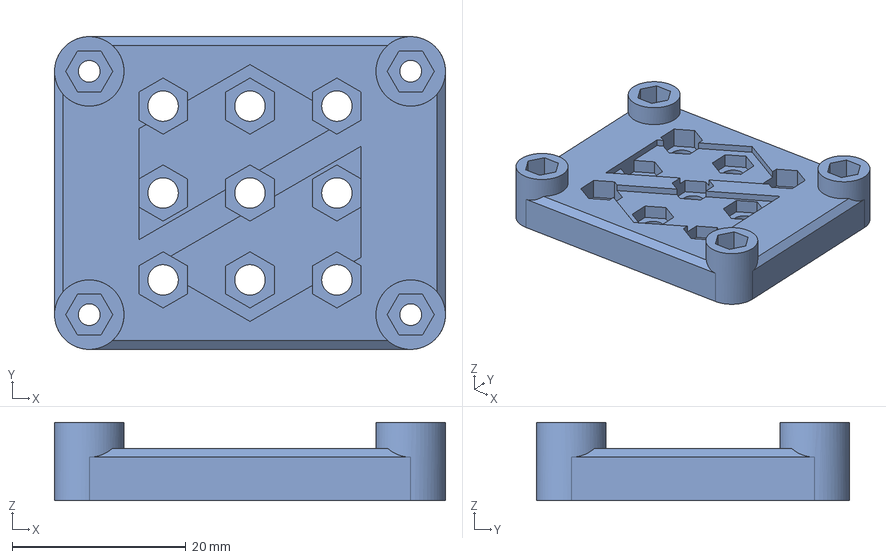
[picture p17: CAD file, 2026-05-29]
design/step/Waveshare Mount.step
45.0 x 36.0 x 9.00 mm

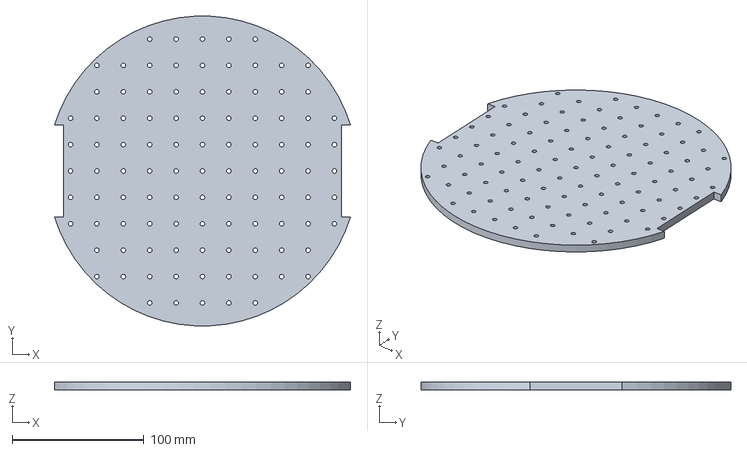
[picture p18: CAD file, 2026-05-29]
design/step/Chassis Base.step
224.3 x 234.7 x 6.00 mm

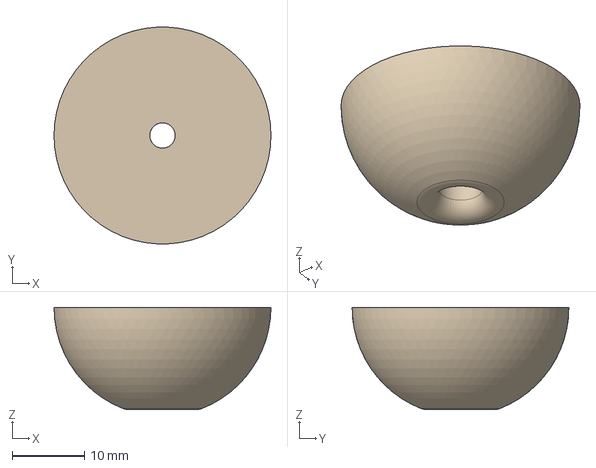
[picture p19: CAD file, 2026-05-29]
design/step/Caster.step
30.0 x 30.0 x 14.1 mm

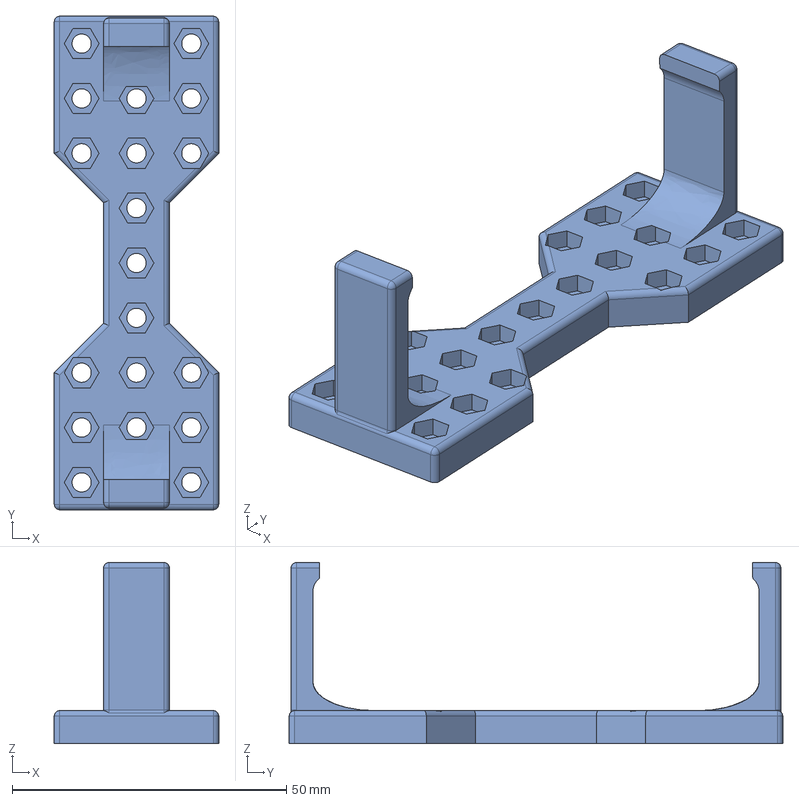
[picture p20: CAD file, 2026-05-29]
design/step/Battery Mount.step
30.0 x 90.0 x 33.0 mm

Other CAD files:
design/step/Wheel with Tyre.step
design/3mf/C1 Lidar Mount.3mf
design/3mf/Camera Mount.3mf
design/3mf/Caster.3mf
design/3mf/Chassis Base.3mf
design/3mf/Chassis Top.3mf
design/3mf/Motor Support.3mf
design/3mf/Waveshare Mount.3mf
design/stl/Battery Mount.stl
design/stl/C1 Lidar Mount.stl
design/stl/Camera Mount.stl
design/stl/Caster.stl
design/stl/Chassis Base.stl
design/stl/Chassis Top.stl
design/stl/Motor Support.stl
design/stl/Pi Bottom.stl
design/stl/Pi Top.stl
design/stl/SO Base ORP.stl
design/stl/Waveshare Mount.stl
design/stl/Wheel Inner.stl
design/stl/Wheel Tyre.stl

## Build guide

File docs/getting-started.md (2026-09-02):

# Getting started

This is the path from a box of parts to a robot that maps a room and drives it.
Steps 1 and 2 run anywhere; from step 3 on you need the hardware, so they run on
the Pi.

If you want to try the software before building anything, skip to
[Simulation](simulation.md) — it needs no hardware and runs the same launch
files.

## Prerequisites

- **The robot, assembled.** Printing, assembly and wiring are covered in
  [Printing & assembly](hardware/assembly.md) and
  [Wiring & power](hardware/wiring.md); the parts list is
  [the BOM](hardware/bom.md).
- **A Raspberry Pi 5 running 64-bit Linux.** Ubuntu 24.04 and Raspberry Pi OS
  Bookworm both work — the
  [Raspberry Pi Imager](https://www.raspberrypi.com/software/) route is
  *Raspberry Pi OS (other)* → *Raspberry Pi OS Lite*. To hand a clean Pi its
  identity, network and build in one shot instead, render a cloud-init image
  with `pixi run provision` (see the [fleet runbook](fleet/README.md)).
- **[pixi](https://pixi.sh) installed.** Everything else — ROS 2 Jazzy, Nav2,
  the drivers — is pulled in by pixi. There is no system ROS install.

## 1. Clone

```bash
git clone --recurse-submodules https://github.com/ClachDev/Mote
cd Mote
```

Forgot `--recurse-submodules`? `pixi run submodules` fetches them afterwards.

## 2. Build

```bash
pixi run build
```

Artifacts land in `build/`, `install/` and `log/`, all git-ignored. If a build
complains about `CMakeCache.txt` naming the wrong source directory (a path
rename, usually), delete `build/` and build again.

Built on your workstation? Copy it to the Pi with `pixi run sync`, or
`pixi run -e dev sync-watch` to keep it copying on every save. Launch files,
config and Python go live without a rebuild (`colcon --symlink-install`); only
C++ needs `pixi run build` again on the Pi.

## 3. Set up the Pi

One time, on the robot:

```bash
pixi run setup
```

That installs the udev rules that give the hardware stable names
(`/dev/mote_servos`, `/dev/mote_lidar`, `/dev/mote_camera`), disables WiFi power
save, and installs the systemd units. The units are installed but **not
enabled** — autostart would flatten the battery on a desk. Opt in when the
robot lives on the floor:

```bash
sudo systemctl enable --now mote-bringup mote-health
```

See [Bringup & reliability](robot/bringup.md) for what those services do, and
what the pre-flight self-check refuses to start without.

## 4. Configure the servos

The drive wheels are expected at servo IDs **7** (left) and **9** (right) at
1 Mbaud. Fresh Feetech STS3215 servos all ship as ID 1, so assign IDs before
first use, connecting one servo at a time when prompted:

```bash
pixi run setup-ids
```

The [servo bus tools](hardware/servo-tools.md) cover the rest of the bus
utilities — pinging, swapping IDs, and calibrating `velocity_scale`.

!!! note "The arm is on the same bus"
    An SO-101 arm's six servos share the wheels' bus at IDs 1–6, so it needs no
    extra electronics — and no udev rule of its own. A serial port has no
    kernel-level exclusion, so exactly one process may hold it, and that process
    is the controller manager. See [the arm docs](arm/index.md).

## 5. Map a space

The stack runs in two phases: build a map with SLAM, then drive it without.

```bash
pixi run mapping   # bringup + SLAM
pixi run teleop    # in another terminal: drive it around
pixi run save-map  # save the map + posegraph into the active site
```

Instead of driving it yourself, `pixi run explore` covers the space
autonomously — run it *on the Pi*, so a WiFi drop cannot end the mission.

`save-map` writes an immutable map revision into the active site's floor, runs a
cleaning pass over it, and validates it. [Sites, maps &
zones](robot/sites.md) explains what a site bundle is, why maps are revisions,
and the three ways a named place gets a coordinate.

## 6. Drive the map

```bash
pixi run robot     # bringup + Nav2 against the saved map
```

Send goals from RViz (`pixi run rviz`, which selects the dev environment), or connect a Foxglove desktop to
`ws://<robot-id>:8765` — the bridge is part of the base bringup, and the shipped
[layout](robot/foxglove.md) has teleop, a map view and the pause control. Teleop
always wins over Nav2 without cancelling the mission; the
[drive path](robot/bringup.md#drive-path--who-gets-the-wheels) explains the
arbitration.

Once places are named, missions become commands:

```bash
pixi run tasks     # the behaviour-tree task layer, alongside `pixi run robot`
```

```bash
pixi run -- ros2 topic pub --once /task/command std_msgs/msg/String \
  "{data: goto kitchen}"
```

See [Missions](robot/missions.md) for the `fetch` and `goto` grammar.

**At this point you have a working robot stack: maps, SLAM, Nav2, teleop and
missions.** From here:

- [Perception](perception/index.md) turns the webcam into obstacles Nav2 can
  see and objects a mission can fetch — with the heavy models on
  [an inference server](inference-server.md) rather than the Pi.
- [The fleet layer](fleet/README.md) puts several robots behind one dashboard,
  with enrollment, dispatch and a shared map registry.
- [Simulation](simulation.md) runs all of it against Gazebo.

## Contributing

A [pre-commit](https://pre-commit.com/) config handles hygiene checks, shell
linting and Python error checking. Wire it in once per clone:

```bash
pixi run lint-install   # into .git/hooks
pixi run lint           # or across the tree by hand (~1 s)
```

To work on these docs:

```bash
pixi run docs           # live-reloading site on http://127.0.0.1:8000
pixi run docs-build     # what CI runs, with --strict
```

AI *aided* contributions are welcome, but only if you can explain and vouch for
every change.

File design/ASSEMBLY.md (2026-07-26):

# Printing & Assembly

How to print the parts and put Mote together. Wiring is covered separately in
[WIRING.md](WIRING.md); the part files live in
[`step/`](step/) (editable in CAD), [`stl/`](stl/) (mesh) and
[`3mf/`](3mf/) (mesh + print setup).

> ⚠️ Print settings below are sensible starting points, not measured-optimal —
> confirm against your printer/filament. The `.3mf` files carry their own plate
> setup; prefer them if your slicer reads 3mf.

## Printing

All parts fit a 256 mm bed (the chassis is 235 mm — see
[design rationale](README.md#chassis-diameter-235mm)).

Suggested defaults: **PLA**, 0.2 mm layer height, 3 walls, 15–20% infill, brim on
the large flat plates to prevent corner lift.

| Part (qty) | Material |
| --- | --- |
| Chassis Base (1) | PLA |
| Chassis Top (1) | PLA |
| Motor Support (2) | PLA |
| Pi Bottom + Pi Top (1 each) | PLA |
| Waveshare Mount (1) | PLA |
| C1 Lidar Mount (1) | PLA |
| Camera Mount (1) | PLA |
| Battery Mount (1) | PLA |
| Wheel Inner (2) | PLA |
| Wheel Tyre (2) | **TPU** (grip) |
| Caster (1) | PLA |
| SO Base ORP (1, optional) | PLA |

Notes:

- **Wheels are two-part**: a rigid `Wheel Inner` hub plus a `Wheel Tyre` printed
  in **TPU** for traction.
- **Caster is unresolved** — printed and several off-the-shelf options have all
  been unsatisfactory so far; treat this part as provisional. A bought ball
  caster of the right height may be preferable (see Assembly step 6).

## Assembly

**Hardware:** the M3 button-head hex set from the [BOM](BOM.md) (screws, nuts)
covers all fasteners. Most joints take **M3×12**: the screw passes through a ~6
mm plate into a part with a ~6 mm captive-nut pocket. Use **M3×10** for thinner
stacks.

> **Note:** I am not convinced yet that screws and nuts are the optimal choice
> here. Nuts have a tendency to loosen up due to vibrations while driving around
> so we may want something more reliable.

Suggested order:

1. **Servos.** Mount each STS3215 to the `Motor Support`, then press a
   `Wheel Inner` onto the servo horn and fit the `Wheel Tyre` over it. Wheels
   are centred and inset so the footprint stays circular. It's easiest to set
   the servo ID's before going further. Left servo is **ID 7**, right is **ID
   9** (assign with `pixi run setup-ids` — see the
   [README](../README.md#4-configure-the-servos)).
2. **Lower plate.** Fasten the `Motor Support`/servos, the `Battery Mount`, the
   `Waveshare Mount`, and the `C1 Lidar Mount`, to the `Chassis Base`.
3. **Caster.** Fit the front `Caster` to the underside of the base for the third
   contact point (provisional — see Printing notes).
4. **Sensors.** Mount the camera in the `Camera Mount`.
5. **Pi cooler.** Fit the Active Cooler to the Pi: peel the thermal pad backing,
   press the spring push-pins through the Pi's two mounting holes, and plug the
   fan cable into the 4-pin `FAN` header. The Pi can already be in its
   `Pi Bottom` holder — just not with `Pi Top` on.
6. **Top plate.** Attach the `Pi Bottom` holder and the `Camera/Camera Mount` to
   the `Chassis Top`.
7. **Close it up.** Fix the `Chassis Top` onto the standoffs.
8. **Power bank.** Seat the power bank in the `Battery Mount` between the
   plates.
9. **Wire it.** Follow [WIRING.md](WIRING.md): bank Out1 → servo board (barrel),
   bank Out2 → Pi, servo board USB → Pi, lidar/camera USB → Pi. Route cables
   through the standoff gap and keep the lidar's 360° view clear.
10. **(Optional) SO-101 arm.** The `SO Base ORP` adapter mounts the
    [SO-101 follower arm](https://github.com/TheRobotStudio/SO-ARM100) on the ORP
    grid.

Then bring the software up per the [main README](../README.md#5-launch).

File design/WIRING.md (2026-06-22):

# Wiring & Power

How the Mote electronics connect. Everything runs from a single USB-C power
bank at **5 V** (see [the 5 V-only rationale](README.md#power-5v-only)). Device
names in the launch stack (`/dev/mote_*`) are created by the udev rules in
[`mote_bringup/udev/`](../mote_bringup/udev/).

Every data link is plain USB (standard male plugs into the device ports), so
there's no special connector wiring — just the cables in the [BOM](BOM.md).
A few electrical details still want bench confirmation; those are marked **Verify**.

## Diagram

```mermaid
flowchart LR
  BANK["UGREEN 140W power bank"]
  BANK -->|"Out1 high-current · USB-C to DC barrel · 5V"| MCB["Waveshare Serial Bus<br/>Servo Driver Board"]
  BANK -->|"Out2 · USB-C to USB-C · 5V"| PI["Raspberry Pi 5"]

  MCB ==>|"3-pin bus: 5V + serial"| SL["Left STS3215<br/>ID 7, inverted"]
  MCB ==>|"3-pin bus: 5V + serial"| SR["Right STS3215<br/>ID 9"]

  MCB -->|"USB serial to /dev/mote_servos"| PI
  LIDAR["RPLIDAR C1"] -->|"USB to /dev/mote_lidar"| PI
  CAM["USB webcam"] -->|"USB to /dev/mote_camera"| PI
  IMU["BNO085 IMU<br/>in testing"] -.->|"I2C to GPIO"| PI

  classDef power fill:#cde,stroke:#369;
  class BANK,MCB,PI power;
```

Solid lines = power and/or wired data. The lidar, camera and IMU are powered by
the Pi over their data connection (USB / GPIO), not from the bank directly.

## Connections

### Power

| From (port) | Cable | To | Carries |
| --- | --- | --- | --- |
| Bank **Out1** (100 W USB-C) | USB-C → DC 5.5×2.1 mm barrel, **5 V** | Servo board DC input | 5 V |
| Bank **Out2** (45 W USB-C)  | USB-C ↔ USB-C, 0.3 m | Pi 5 USB-C power in | 5 V |
| Servo board | 3-pin servo lead | Left STS3215 (**ID 7**)  | 5 V |
| Servo board | 3-pin servo lead | Right STS3215 (**ID 9**) | 5 V |

### Data

| From | Cable | To | Device node | Notes |
| --- | --- | --- | --- | --- |
| Servo board (USB-C data) | USB-A ↔ USB-C, 0.3 m | Pi USB-A | `/dev/mote_servos` | CH343 USB-serial, 1 Mbaud |
| RPLIDAR C1 | USB (cable supplied with unit) | Pi USB-A | `/dev/mote_lidar`  | 460800 baud; powered over USB |
| USB webcam | USB-A (captive) | Pi USB-A | `/dev/mote_camera` | UVC; powered over USB |

The Pi 5 has 4 USB ports (2× USB-3, 2× USB-2). Servo board, lidar and camera
take three of them.

## Power notes (the fiddly bit)

Three things make the 5 V budget non-obvious:

1. **Servos run at 5 V** The STS3215's
   [datasheet](https://www.feetechrc.com/Data/feetechrc/upload/file/20260622/6391772523943436695270694.pdf)
   operating range is **4 V - 7.4V**, with the expected value of 6V or 7.4V.
   Mote feeds the servo board **5 V** and this seems to work well. Just don't
   expect the datasheet torque numbers, since those are quoted at the higher
   voltage.

2. **A "100 W" USB-C port is not 100 W at 5 V.** USB-C PD allows devices to
   negotiate different voltage/current depending on need. Focusing on 5V, the
   spec allows requesting up to 3A, however it is common for supplies to allow
   up to 5A. The Pi explicitly requests 5V/5A = 25W. The servos only need 500mA.

### Rough 5 V budget

| Load | Rail | Typical | Peak | Fed from |
| --- | --- | --- | --- | --- |
| Raspberry Pi 5 | 5 V | 5–10 W | 25 W (5 V/5 A) | Out2 |
| 2× STS3215 (driving) | 5 V via board  | 1-2 W (130mA no load) | 10W (2A stall) | Out1 |
| RPLIDAR C1 | 5 V via Pi USB | 1.15 W (230 mA) | — | Pi |
| USB webcam | 5 V via Pi USB | ~0.5–1 W | — | Pi |

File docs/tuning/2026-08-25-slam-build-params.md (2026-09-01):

# Build params for an offline map solve — evidence

`mote_bringup/config/slam_toolbox_build_params.yaml` is the parameter set the
mapping pipeline's build stage solves a recorded bag under, as against the live
file the robot captures with. This is the measurement of which keys earned the
right to differ.

The answer is one key, and not the one the design expected.

Bag: `20260802_142539`, the 2026-08-02 flat mapping session — 542 fed scans,
340 pose-graph nodes, and the only bag on hand whose robot physically returned
to its start, so the only one where loop drift means anything. Harness:
`pixi run bag-replay --lockstep` (21 s per leg). Raw output in
`2026-08-25-slam-build-params/`.

## 0. Lockstep replay is deterministic

Two legs of one parameter set, launched separately under different
`ROS_DOMAIN_ID`s, returned identical metrics to every digit printed — drift
0.108 m, path 139.77 m, speckle 0.0195, the same wall-direction table. The
harness README warns that "SLAM's solver is not bit-exact run-to-run; treat
small deltas as noise", which is the right caution for a paced replay; under
lockstep, on this bag, it did not bite.

That matters for everything below: a 0.01 m difference between two parameter
sets is a real difference, not spread. It also retires a reading of the
2026-08-02 session's six same-named legs (drift 0.088–0.107 m) as a noise band.
They differed by the yaw each had injected, not by chance.

## 1. `loop_match_minimum_chain_size` — the one real divergence

Live is 15, and 15 cannot be satisfied at `loop_search_maximum_distance: 2.0`.
A straight pass through a 2.0 m-radius disc gives a 4.0 m chord;
`minimum_travel_distance: 0.3` puts nodes 0.3 m apart along it; so the longest
chain a pass can contribute is about 13. Closure candidates never form, at any
drift.

| chain | loop drift | map |
| --- | --- | --- |
| 15 (live) | 1.365 m | torn — duplicated hallway, three living-room copies |
| 10 | 0.087 m | coherent |

Measured 2026-08-02 at commit `dabffca`
(`bag_replay_results/20260802T142558Z`) and reproduced here under the committed
build file: 0.087 m.

This is a divergence only until task 335 lands, which moves the live file to 10
for the same reason. `test_slam_build_params.py` fails when it does, naming the
key and saying to delete the note — the live config is best-known-good by
policy, so a build-only correction to it is a temporary state, not a design.

## 2. `coarse_angle_resolution` — rejected

The 2026-08-02 map shipped at 0.0175 (1.0°) against the live 0.0349 (2.0°), on
the reasoning that the coarse sweep snaps a solution to a 2° orientation
lattice and so puts wall alignment out of reach. **There is no such lattice.**

Karto's `ScanMatcher::MatchScan` (slam_toolbox 2.8.5,
`lib/karto_sdk/src/Mapper.cpp`) runs the coarse sweep, then a fine pass:

```cpp
bestResponse = CorrelateScan(pScan, rMean, fineSearchOffset, fineSearchResolution,
    0.5 * m_pMapper->m_pCoarseAngleResolution->GetValue(),   // searchAngleOffset
    m_pMapper->m_pFineSearchAngleOffset->GetValue(),         // searchAngleResolution
    doPenalize, rMean, rCovariance, true);
```

The fine pass searches ±half the coarse step in increments of
`fine_search_angle_offset` — that is, it covers the coarse cell exactly. At the
live values it samples 11 angles across ±1.0° at 0.2° spacing. The reachable
set is a contiguous 0.2° grid whatever the coarse value, and 0.2° —
`fine_search_angle_offset` — is the quantum either way. Halving the coarse step
does not refine the answer; it only moves where the fine pass starts.

Measured, three values × two alignment conditions, everything else held at the
committed build file:

| `coarse_angle_resolution` | drift, birth-aligned | drift, unaligned | wall thickness |
| --- | --- | --- | --- |
| 0.0349 (live, 2.0°) | **0.099 m** | **0.087 m** | **0.064 m** |
| 0.0175 (1.0°) | 0.098 m | 0.097 m | 0.065 m |
| 0.01745 (1.0°, integral) | 0.108 m | 0.109 m | 0.065 m |

Birth-aligned legs ran `--frame 0 0 -3.0`, reproducing the shipped build; the
0.0175 leg returns 0.098 m against the shipped revision's recorded
`loop_drift_m: 0.098`, so the pipeline reproduces.

The live value wins or ties on drift in both conditions and on wall thickness
in both. Speckle prefers 0.0349 aligned (0.0136 vs 0.0159) and 0.01745
unaligned (0.0172 vs 0.0192) — it disagrees with itself and decides nothing.
`wall frames` reads 1 for 0.01745 aligned only because that map's second frame
carries 0.143 of the energy against the report's 0.15 threshold; the frame is
still there in the per-map table. No candidate beat the live value, so
`coarse_angle_resolution` does not diverge.

One aside, since it looks like a reason to prefer 0.01745 and is not:
0.01745 is exactly 5 × `fine_search_angle_offset`, which keeps the fine
sweep's sample count integral and satisfies the assert at the end of
`ComputeAngularCovariance` (`Round(2·offset/resolution)` must land the last
sample on `centre + offset`). 0.0175 does not — the ratio is 5.014 — so that
assert would trip in a debug build. Release builds compile it out, which is why
the shipped map solved without complaint. It is a real latent trap, and moot:
0.01745 scored worst of the three.

## 3. `loop_search_maximum_distance` — rejected

Widening the loop search does not beat radius 2.0 paired with chain 10.
Measured 2026-08-02 at `dabffca`, same bag, unaligned:

| radius | chain | other | loop drift |
| --- | --- | --- | --- |
| 2.0 | 10 | — | **0.087 m** |
| 3.5 | 10 | — | 0.094 m |
| 5.0 | 15 | — | 0.531 m |
| 8.0 | 12 | `loop_search_space_dimension: 12.0` | 1.561 m |

## What this leaves

The build file differs from the live file in one key, and only until the live
file catches up. That is the correct outcome of the pipeline's own rule — the
live config is never deliberately hobbled, so there is little left for a build
to improve by parameter alone. What the build actually buys is *steps* the
robot cannot run: a second solve with a measured yaw injected, prominence-based
declutter, room segmentation, and a human looking at the result before it is
promoted.

The file still earns its place as the seam those steps point at, and as the
record above — so the next person to wonder whether a finer angular sweep helps
can read that it was tried, and why it cannot.

## Limits of this measurement

- **One bag, one building.** A flat with four wall families. The conclusion
  drawn is the conservative one (do not diverge), which is the safe direction to
  be wrong in, but a warehouse or a long corridor could move it.
- **Loop drift needs a closed trajectory**, which most mapping sessions do not
  have. See the harness's own limitations note, reproduced in each report.
- **Angular residual below ~2° is not measurable** with `wall_rotation` — its
  docstring records the floor and the under-reporting below it. Whether a
  finer sweep helps the *alignment* step specifically therefore remains
  unmeasured; it is not evidence for a divergence, it is an absence of it.
  Followed up in `2026-09-01-alignment-residual.md`, which measures these very
  maps: `wall_rotation` calls all seven square and four of them are 3.5–5.6°
  out, so the limit above is generous. That does not move the conclusions here,
  which rest on drift, wall thickness and speckle.

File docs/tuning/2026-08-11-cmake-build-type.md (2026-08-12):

# Where the C++ optimisation flags come from, 2026-08-11

**Verdict: `pixi run build` passes `-DCMAKE_BUILD_TYPE=Release`, and it changes
nothing measurable.** An empty `CMAKE_BUILD_TYPE` in `build/*/CMakeCache.txt`
looks like an unoptimised robot and is not one — which is the thing worth
recording here.

Empty means CMake appends no `CMAKE_CXX_FLAGS_<CONFIG>`; it does not mean `-O0`,
because `CMAKE_CXX_FLAGS` is seeded from the environment's `CXXFLAGS` and the
conda compiler packages export one — `-O2` on linux-64, **`-O3` on
linux-aarch64**. mote-01's real compile lines carried `-O3` before this change.
`kinematic_icp` was never in question either: its own CMakeLists does
`set(CMAKE_BUILD_TYPE Release)` (`ros/CMakeLists.txt:26`), shadowing the cache,
so its objects already had `-O3 -DNDEBUG`.

So the flag adds `-DNDEBUG` on the robot and takes linux-64 from `-O2` to `-O3`.
Its point is that the level is now stated by the repo rather than inherited from
whichever toolchain the solve picked, and survives a build outside pixi.
**Not `RelWithDebInfo`**: config flags are appended *after* `CXXFLAGS`, so its
`-O2` would beat the Pi's `-O3` and lower optimisation.

## Measured

Replaying mapping bag `20260729_160009` into `localization_launch.py`
(`use_sim_time:=true`) drives the real ICP at the recorded 10.0 Hz, identical
input each run, so only the binary differs. Container `utime + stime` over a
120 s window, 3 reps a side, rebuild between:

| | mean CPU-s / 120 s | mean ms per scan |
| --- | --- | --- |
| before | 2.207 | 1.837 |
| after | 2.200 | 1.831 |

−0.3% against a ±0.7% within-group spread: no effect, as expected from flags
that barely moved. Also worth knowing: the whole container costs **1.8% of one
core**, so it is not where a nav mission's load goes.

## `-ffp-contract=off` survives Release

`odom_tf_relay`'s bit-identity against the Python it replaced depends on that
flag (`mote_nav/CMakeLists.txt:60`), and Release now stacks `-O3` over it.
Target options are emitted last, so it still wins — counted in the shipped
aarch64 objects, not inferred: `libodom_tf_relay_component.so` holds **0** fused
multiply-adds before and after, while `libicp_odom_gate_component.so` (same
`-O3`, no flag) holds **11** both times, so the zero is the flag and not a
target without FMA. `test_odom_tf_relay.cpp` cannot catch this — it compares the
relay against reference arithmetic in the same TU, under the same flag.

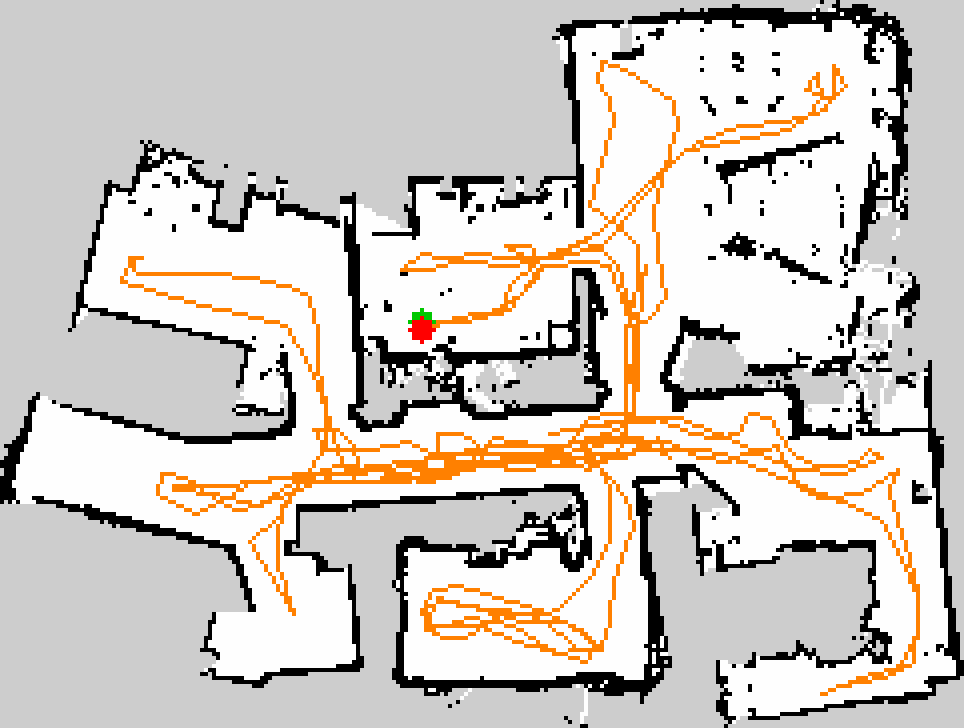
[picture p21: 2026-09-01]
docs/tuning/2026-08-25-slam-build-params/unaligned/car-0.0175/map.png

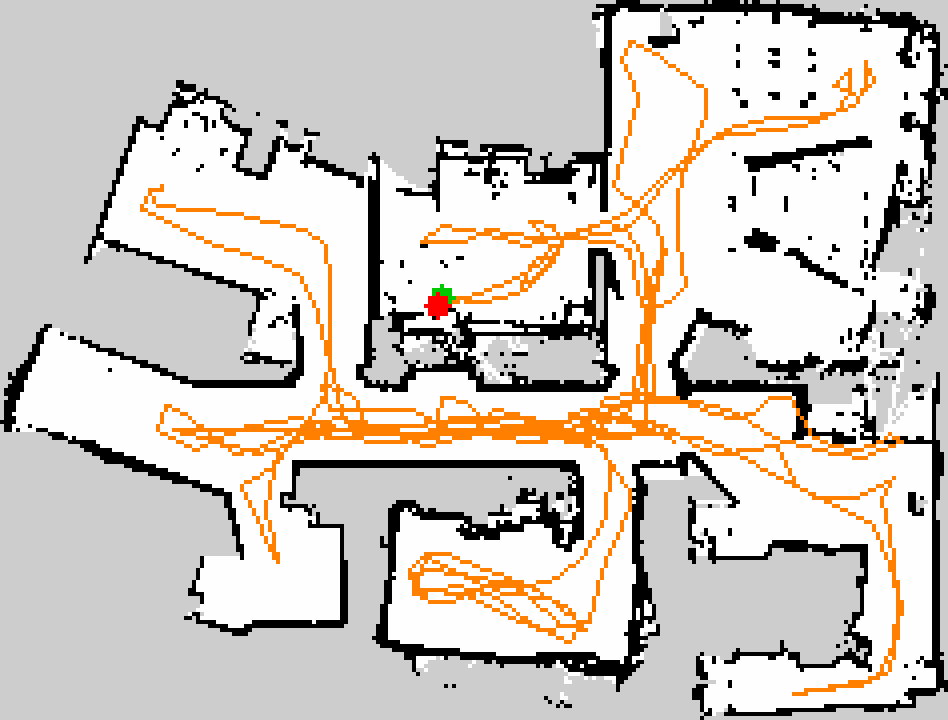
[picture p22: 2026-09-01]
docs/tuning/2026-08-25-slam-build-params/birth-aligned/car-0.01745-repeat/map.png

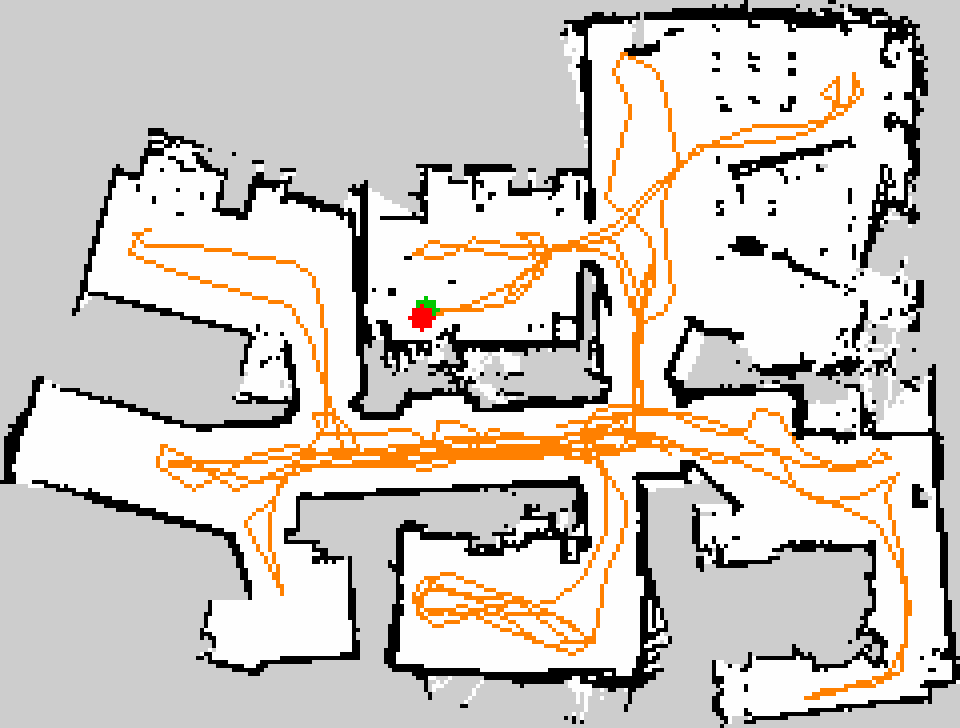
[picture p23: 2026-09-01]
docs/tuning/2026-08-25-slam-build-params/birth-aligned/car-0.0349/map.png

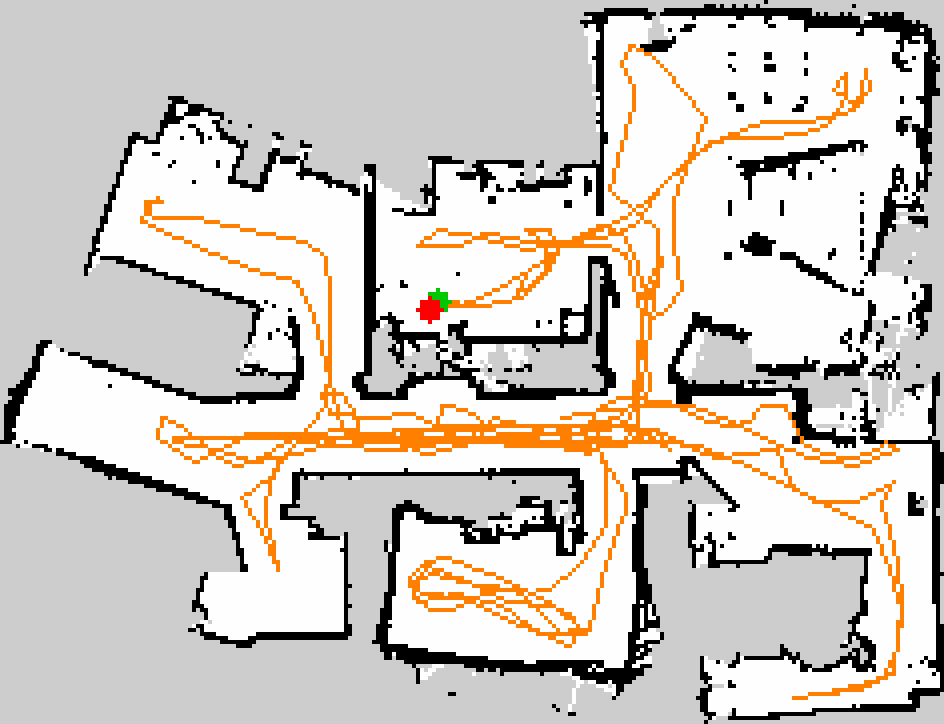
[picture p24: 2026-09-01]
docs/tuning/2026-08-25-slam-build-params/birth-aligned/car-0.0175/map.png

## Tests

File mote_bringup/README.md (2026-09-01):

# mote_bringup

Launch files, config, udev rules, NetworkManager drop-ins, and systemd services
for the robot. The package layout and launch hierarchy are documented in the
top-level `CLAUDE.md`; this README covers the **on-robot reliability stack** —
how the robot survives unattended operation.

## Starting the robot

**By hand (the normal way):** `pixi run robot` (nav) or `pixi run mapping`. Both
include the health monitor, so `/health` and `/diagnostics_agg` are published on
any manual run — one command, nothing else to start.

**Unattended:** the systemd units below. They are installed by `pixi run setup`
but **not enabled**, because starting the drive stack and recorder on every boot
drains the battery of a robot that is just sitting on a desk, and the recorder's
pruner trims older bags whenever it runs. Opt in per robot:

```bash
sudo systemctl enable --now mote-bringup mote-health   # autostart at boot
sudo systemctl disable mote-bringup mote-health        # back to manual
```

## Mapping a space autonomously

`pixi run explore` drives autonomous coverage against a live mapping mission:
left-wall following for dense boundary tracing, a Nav2 frontier relocation when
the map stops growing, and a stuck-escape (back off, turn away, blacklist the
spot) for obstacles the 2D lidar cannot see — rug edges, cables, low clutter.
It exits when no reachable frontier remains, then the map is saved like any
other session. The sim builds its world sites with the same tool (`pixi run
sim-map-world`, which passes `--sim-time`).

It publishes the drive mux's *teleop* input (see the drive path below) — it
stands in for a human driver, so its wall-follow out-ranks the Nav2 goals it
hands off during relocation. A human on the Foxglove stick shares that input
with it, last writer wins — stop the explorer before driving by hand.

**Run everything on the Pi**, in tmux, so losing wifi only loses your view of
the mission — never the mission:

```bash
ssh <robot> tmux new -s map
pixi run mapping      # window 1
pixi run explore      # window 2 — watch progress via Foxglove
pixi run save-map     # when it reports covered
```

The default thresholds suit corridor-scale spaces. Domestic layouts (~0.75 m
doorways) want the geometry tightened, e.g.
`pixi run explore -- --cruise 0.2 --obstacle 0.4 --desired-left 0.6 --follow-band 1.0 --blacklist-radius 1.0`.

If the scan stream goes stale (wedged graph, dead lidar) the explorer stops
and waits rather than driving blind. The graph itself cannot be stalled by
wifi: DDS transport is **loopback-only by default** (`config/cyclonedds.xml`,
loaded through `CYCLONEDDS_URI` by pixi activation and the systemd units
alike), because Cyclone otherwise prefers a radio interface's locators even
between processes on the same board, and a wifi flap then freezes same-host
scan delivery. Foxglove still works (it is a WebSocket server, not a DDS
peer); RViz-over-LAN does not — Foxglove is the supported window. One gotcha:
a stale `ros2` daemon from a different environment will show an empty graph
until `pkill -9 -f '[_]ros2_daemon'`.

## Drive path — who gets the wheels

`DiffDriveController` has exactly one publisher: `twist_mux`, started with the
base by `twist_mux_launch.py`. Everything that wants to move the robot publishes
an input instead, and the mux forwards the highest-priority source that has
spoken recently:

| Input | Published by | Priority | Timeout |
|---|---|---|---|
| `/cmd_vel_nav` | Nav2's `controller_server` and `behavior_server` | 10 | 0.5 s |
| `/cmd_vel_teleop_stamped` | `twist_relay` (Foxglove panel), `pixi run teleop`, the RViz teleop panel | 100 | 1.0 s |

Priorities and timeouts live in `config/twist_mux.yaml`; the output is
`/diff_drive_controller/cmd_vel`, unchanged, so bags, the benchmark and the sim
smoke test still watch the command the wheels actually got.

Before this, teleop and Nav2 both wrote the controller's topic and it simply took
whichever arrived last — so taking over by hand during a goal meant two writers
at 20 Hz and a robot tracking neither, and the documented remedy was "cancel the
task first", which is the wrong instruction for someone grabbing control of a run
that is going wrong.

**Teleop overrides Nav2; it does not cancel it.** The mux is a drive-path
component, and cancelling a goal from it would wire velocity arbitration into the
action layer — a nudge to straighten the robot in a doorway would destroy a fetch
mission halfway through. So a takeover suppresses Nav2 for as long as the
operator is driving, and the goal is still there afterwards.

**Letting go stops the robot before Nav2 gets it back.** That is what the teleop
input's 1.0 s timeout buys, against the controller's `cmd_vel_timeout` of 0.5 s
(`controllers.yaml`): after the operator's last command the wheels halt at 0.5 s
and Nav2 only regains the topic at 1.0 s, so there is always a stopped robot in
between rather than a handback mid-motion. Invert the two numbers and that
property is gone silently, so `test_twist_mux.py` holds the two files together
and `test_twist_mux_arbitration.py` measures the gap against a real mux
(1.00–1.05 s over five takeovers; pre-emption itself lands within one 20 Hz
publish period, ~50 ms).

**The deadman is unchanged.** `twist_mux` publishes from an input callback and
only when that input holds priority — no timer, no stored last command — so when
every source stops the mux stops and `cmd_vel_timeout` halts the wheels, exactly
as when the sources wrote the controller directly. A mux that re-published would
have turned "the operator's link dropped" into "the robot keeps going"; that it
does not is asserted, not assumed.

**To hold autonomy off entirely**, publish `std_msgs/Bool` on `/pause_navigation`
— `true` masks every source below priority 50, which is navigation and not
teleop, and `false` hands it back. The shipped Foxglove layout has a Publish
panel for it. The lock is state rather than a heartbeat (timeout 0.0), so it does
not engage when its publisher goes away and a restarted mux starts unlocked. Note
what a long pause does to the *mission*: Nav2's `SimpleProgressChecker` gives the
robot `movement_time_allowance` (10 s) to move `required_movement_radius`, so a
goal held off the wheels while the robot sits still aborts itself, and the task
reports failed. Driving under teleop keeps it alive, since the checker watches
the robot's pose and not who commanded it.

Cost is one process and **one DDS participant** (measured with
`pixi run dds-check`), putting the full robot stack at ~26 of 33.

## Wifi roaming

The robot changes access point as it drives between rooms because the Broadcom
firmware's roaming engine is on: `options brcmfmac roamoff=0`, the driver's own
default, which Raspberry Pi OS overrides. Neither iwd nor wpa_supplicant will
take that decision on this card, for reasons in their source rather than their
configuration — `wifi/README.md` quotes both.

```bash
pixi run wifi-check     # what takes the roam decision (read-only)
pixi run wifi-roaming   # write the modprobe option; takes effect at next boot
pixi run wifi-roamlog   # log BSSID/signal/RTT during an acceptance walk
```

The trigger is -75 dBm with a 20 dB delta, compiled into the driver and not
tunable. What to do if that is wrong for a site, and the measurements behind all
of it, are in [`wifi/README.md`](wifi/README.md).

## systemd services

Installed by `pixi run setup` (→ `systemd/install.sh`), which fills in the
invoking user/home/repo. Boot order once enabled:

```
mote-bringup  →  mote-slam  →  mote-nav
  │  (self-check runs here      ↘  mote-record
  │   as ExecStartPre)          ↘  mote-health
```

`mote-bringup` runs the self-check as its `ExecStartPre` gate — there is no
separate self-check service; gating bringup gates everything downstream.

| Service | Runs | Notes |
|---|---|---|
| `mote-bringup` | `pixi run launch health:=false foxglove:=false` | Hardware base. `ExecStartPre` runs the self-check gate first; the two `false`s are because `mote-health` and `mote-foxglove` run those separately here. |
| `mote-slam` | `pixi run slam` | `BindsTo`/`PartOf` bringup — restarts with it. |
| `mote-nav` | `pixi run nav` | `BindsTo`/`PartOf` slam. |
| `mote-record` | `pixi run record` | `After`/`PartOf` bringup (no `Wants` — see below); a recorder crash never takes down the drive stack. |
| `mote-health` | `pixi run health` | Health monitor; `Type=notify` + `WatchdogSec` watchdog. `After=` only, so it keeps observing across a bringup restart. |
| `mote-foxglove`  | `pixi run foxglove` | The operator's remote view + teleop (`docs/fleet/README.md` §10). `After=` only, for the same reason as the monitor: a crash-looping mission is when someone needs to look at it. |
| `mote-agent` | `pixi run agent` | Fleet bridge (`docs/fleet/README.md` §7). `After=` only. |

All of these also pin DDS to the robot
(`ROS_AUTOMATIC_DISCOVERY_RANGE=LOCALHOST`), so a robot running under systemd is
not visible to a workstation's ROS graph — `mote-foxglove` is the replacement.
An interactive `pixi run` keeps stock discovery.

**Hardening** (all services):

- `Restart=always` with backoff (`RestartSec=2`, `RestartSteps=5`,
  `RestartMaxDelaySec=30`): a crashed service restarts, backing off from 2 s to a
  30 s ceiling instead of hammering.
- `StartLimitIntervalSec=0`: never permanently give up. An unattended robot must
  self-heal when reconnected hardware reappears; the backoff prevents a busy
  loop, so there is no reason to latch into a failed state.
- **Device ordering**: the udev rules tag the servo/lidar devices
  `TAG+="systemd"`, so systemd synthesises `dev-mote_servos.device` /
  `dev-mote_lidar.device`. `mote-bringup` orders `After=` / `Wants=` them, so
  bringup waits for the hardware to enumerate but a mid-run flap does not
  force-kill the stack (the self-check and health monitor own that).
- **journald sizing**: `systemd/journald-mote.conf` bounds the persistent
  journal (`SystemMaxUse=500M`, `SystemKeepFree=1G`, `MaxRetentionSec=2week`) so
  always-restarting services can never fill the SD card.
- **No `Wants=` on the dependents.** `mote-health` and `mote-record` order
  `After=` bringup but never *pull* it. A `Wants=` dependent that is itself
  restart-looping fires a start request for bringup every cycle, and such a
  request **bypasses bringup's own `RestartSec` backoff** — systemd logs
  "Scheduled restart job immediately on client request". Measured on the robot:
  bringup then restarts at the dependent's rate rather than its own backoff.
  Each unit is started at boot by its own `WantedBy=multi-user.target`.
  `mote-slam`/`mote-nav` keep `Requires=`/`BindsTo=` because they are genuinely
  meaningless without bringup, and `BindsTo` holds them stopped (rather than
  looping) while it is down.
- **Units run from the checkout they were installed from**, via `@REPO@`
  substituted by `install.sh` from its own location — not a hardcoded `~/Mote`.
  Installing from a second checkout otherwise yields units pointing at a tree
  that may not contain the tasks they invoke (`status=127`, permanent loop).

**Three layers of process recovery** (see also `test/chaos/`):

1. **Process crash** → the launch system relaunches just that process
   (`respawn=True` on the drivers in `mote_launch.py` and on the Nav2 container
   in `nav2_launch.py`). Nav2 is composed, so its granularity is the whole stack
   rather than the individual server: the container respawns, the launch file
   reloads the components into it, and the lifecycle managers — components
   themselves — re-activate everything on the way back up.
2. **Launch/process crash** → systemd restarts the whole service.
3. **Health-monitor hang** → the `WatchdogSec` watchdog restarts `mote-health`.

## Startup self-check — `self_check.py`

Runs as `mote-bringup`'s `ExecStartPre` (and by hand: `pixi run self-check`).
Fast, static pre-flight checks — no ROS graph — that gate the launch:

- **servos**: bus device present *and* an SCServo ping answers (`servo_ping`, the
  drive IDs from `robot.yaml`) — CRITICAL.
- **lidar**: device present and openable — CRITICAL.
- **camera**: device present and openable — advisory.
- **disk**: free space on `MOTE_HOME` (< 500 MB CRITICAL, < 2 GB warn).
- **clock**: system time looks NTP-synced (an RTC-less Pi boots at the epoch) —
  advisory.
- **config**: `robot.yaml` parses (CRITICAL); an active site is resolved
  (advisory — mapping runs without one).

Any failed **CRITICAL** check → non-zero exit → the `ExecStartPre` fails →
bringup does not start (robot stays in safe idle) and systemd retries with
backoff, so replugging the lidar recovers on its own. The verdict is written to
`$MOTE_HOME/self_check_status.yaml` and printed to journald.

Runtime data-flow liveness (is `/scan` *publishing*?) is deliberately **not**
checked here — the drivers are not up yet. That is the health monitor's job.

## Host monitor — `system_monitor.py`

Started by `mote_launch.py`, so every mission bag carries the compute context:
CPU busy/load, memory, SoC temperature, fan RPM, and the Pi firmware's
`get_throttled` bitfield, published on `/diagnostics` as the `system` status.

**Throttle flags come from `vcgencmd get_throttled`, not sysfs.** The Pi 4
device-tree node (`/sys/devices/platform/soc/soc:firmware/get_throttled`) does
not exist on a Pi 5, so the sysfs read this monitor used to do was dead code —
the robot spent a whole nav mission at 85 °C without the ERROR ever firing. The
binary needs the invoking user in the `video` group (the `mote-*` service user
is). Off a Pi, `shutil.which` finds nothing and throttle reporting is skipped.

Four conditions are reported, each as a `_now` and a latched `_ever` key
(firmware bits 0–3 and their has-occurred latches at 16–19):
`undervoltage`, `freq_capped`, `throttled`, `soft_temp_limit`. Any `_now` bit
raises **ERROR** with a `power: …` message naming the conditions; the `_ever`
keys and the raw `throttled_flags` hex are informational. `soft_temp_limit` is
the sustained-85 °C case specifically — hard throttling (bit 2) is not always
asserted at the instant you sample, so keying only off it misses the event.

`fan_rpm` is the Active Cooler's tachometer, found by scanning
`/sys/class/hwmon/*/name` for `pwmfan` (hwmon indices are not stable across
boots). With no cooler fitted the key is simply absent. Measured on `auldbot`:
idle 48 °C / 0 RPM, 4-core load 61 °C / ~4900 RPM with no throttle bits set.

## Slip monitor — `slip_monitor.py`

Started by `mote_launch.py`, beside `system_monitor`. It reads the disagreement
between the robot's two motion sources and publishes what it means as the `slip`
status on `/diagnostics`, which the health monitor folds into the roll-up.

kinematic_icp *takes* wheel odometry as its prior and corrects it against the
scan, so the correction is already a measurement of how wrong the wheels were —
a slip signal on existing hardware, with no IMU. Over a 1 s sliding window the
node compares the travel each source reports, in the body frame, and reports:

| state | meaning |
|---|---|
| `slip` | The wheels claim travel the lidar did not see. Wheels spinning on a slippery floor, or a robot wedged against something. |
| `stuck` | Motion is commanded and *neither* source reports any. |
| `icp_fault` | The lidar pose moved in a way the drive cannot produce. Slip makes the wheels over-read, never the lidar, so this is a scan-match excursion — or the robot being moved by hand. |

All three are **DEGRADED**, never FAULT: each is a reason to stop and re-plan,
not a reason to refuse to drive, and a monitor that can halt the robot on a
threshold is a worse failure than the slip it is watching for.

`slip/residual` (`geometry_msgs/TwistStamped`) carries the raw numbers so they
can be recorded and plotted: `linear.x` is the speed residual (wheel minus
lidar, m/s), `linear.y` the speed it is relative to, `angular.z` the yaw-rate
residual.

Three things are worth knowing:

- **Only translation is thresholded.** The yaw residual is published but never
  keyed off: measured on real bags it is dominated by scan-match jitter, reaching
  a p99 as large as the yaw rate itself, so no threshold exists that a hard turn
  would not trip. Translation on the same bags has a p99 of 0.006–0.021 m/s.
- **A stalled lidar is not slip.** Without a guard, a stopped corrector freezes
  the window while the wheels keep turning, which grows without bound and looks
  exactly like slip. A source older than `max_lag` yields no verdict instead.
- **Thresholds are measurements, not guesses.** They come from the residual
  distribution over `~/.mote/bags/mapping`, live in `config/slip.yaml`
  (overridable at `$MOTE_HOME/slip.yaml` — traction is a property of one robot on
  one floor), and are re-checkable with `tools/slip_replay.py`, which drives the
  very same estimator over a bag. The derivation, and the six real events it
  found in those bags, are in `docs/tuning/2026-07-28-slip-detection.md`.

## Health monitor — `mote_health`

Lives in its own package now, and is C++: what a monitor costs is how often it
is woken, and this one consumes ~152 msg/s, which no rclpy callback can afford.
The evidence is `docs/tuning/2026-08-11-monitor-cpu.md`, the port
`docs/tuning/2026-09-01-health-monitor-cpp.md`, and the package's own
`mote_health/README.md`. What it decides is unchanged and is summarised here
because it is read alongside the other monitors above.

Runs as `mote-health.service` (or `pixi run health`). Watches subsystem liveness
and publishes, every second:

- **`/diagnostics_agg`** (`diagnostic_msgs/DiagnosticArray`) — one
  `DiagnosticStatus` per subsystem (scan, filtered scan, joint states, camera,
  odom TF, localisation TF), the `system` and `slip` statuses folded in from the
  shared `/diagnostics`, the last self-check verdict, and a rolled-up `mote`
  status. The standard form the fleet layer can lift later.
- **`/health`** (`std_msgs/String`) — a single human-readable summary line:
  `OK` / `DEGRADED: camera stale` / `FAULT: scan stale (…)`. Easy to eyeball:

  ```bash
  pixi run -- ros2 topic echo /health
  ```

**Severity → roll-up**, set per subsystem in `mote_health/config/health.yaml`
(overridable per-robot at `$MOTE_HOME/health.yaml`, the same rule `mote_home`
holds for Python):

| `severity` | Missing/stale means | Used for |
|---|---|---|
| `critical` | **FAULT** | scan, filtered scan, joint states, odom TF — cannot drive without them |
| `degraded` | **DEGRADED** | camera — capability lost, driving still safe |
| `info` | reported, never degrades | `map→odom`, which exists only once a mission localises |

A fresh-but-slow subsystem degrades one step at most (never above its own
severity). `info` exists because the hardware base alone legitimately has no map
frame: scoring that as DEGRADED made a healthy idle robot report DEGRADED
forever. Mission localisation health belongs to the nav2 lifecycle, not here.

Two things worth knowing about these thresholds:

- The `joint_states` 5 Hz floor detects a control loop that is overrunning; it
  is not a rate spec (`controller_manager` runs at 50 Hz). An unresponsive servo
  bus blocks each `read()` ~200 ms per servo and collapses the loop to ~1.6 Hz,
  which the driver itself reports only as warnings.
- `/diagnostics` is a **shared** topic: `controller_manager` publishes its own
  loop-jitter status there. Statuses are therefore lifted by exact name, listed
  in `health.yaml`'s `diagnostic_statuses` (`system`, `slip`), or a third party's
  ERROR gets misattributed to one of ours and drives a spurious robot-level
  FAULT. A named status nobody is publishing is simply absent — asserting
  another monitor's liveness is not this monitor's job.

The monitor is also the systemd watchdog feeder: it sends `READY=1` once up and
pets the watchdog on every publish (`mote_health/src/sd_notify.cpp`, a
dependency-free `$NOTIFY_SOCKET` client that no-ops outside systemd). It moved
with the monitor rather than being copied: `mote-health.service` is the only
`Type=notify` unit, so nothing here was left needing the Python one.

## Clearing stray ROS processes — `sweep_orphans.py`

Two different messes, one module, and the difference is worth knowing before
reaching for either.

`pixi run kill` clears **this checkout's** ROS processes and resets the daemon —
the "my stack is wedged" reset. `pixi run sweep` clears **other jobs'** leftovers:
processes an agent worktree started and never reaped, which reparent to init and
run until the box is rebooted. It reports by default and only acts with `--kill`:

```bash
pixi run sweep                 # what would go, grouped by the job that left it
pixi run sweep -- --kill       # reap them
pixi run sweep -- --json       # for a script
```

That second mess is not just untidiness. Leftovers are the exact process names a
benchmark measures, and the system-wide counters a benchmark sits in — context
switches, interrupts, memory pressure, CPU contention — cannot be scoped the way
`overhead.py` scopes its own match. A drifting background makes every
measurement on the box a little less comparable than it looks.

**Matching is on process identity, never on the command line.** The `pkill -9 -f
'<driver names>'` that `kill` used to run matched the shell running the task
itself — those names are in its own command line — SIGKILLed it, and so never
reached the `ros2 daemon` reset that followed; it also matched every other
checkout and worktree on the machine. Both modes now read `/proc` and require a
ROS environment, a path under the directory in question, and absence from the
sweeper's own ancestry. The sweep additionally requires that the process be
orphaned and older than `--min-age` (30 min), because a deliberately
session-detached run — the sim smoke test `setsid`s its launch — is
indistinguishable from a leak by ancestry alone.

### Why they escape

`ros2 run` is a wrapper: it `Popen`s the real executable and installs no SIGTERM
handler, tolerating only `KeyboardInterrupt` on the assumption that the signal
reached the whole process group — true of a Ctrl-C at a terminal, false of a
`proc.terminate()` from a test fixture. Terminating the wrapper therefore kills
the wrapper and hands the node to init, **once per run, on the path where the run
succeeded**. Measured on `test_twist_mux_arbitration.py`: six tests pass and one
`twist_mux` survives.

So anything spawning `ros2 run` uses `spawn_reapable` / `reap_group` from
`sweep_orphans`, which put the child in its own session and signal the group.
The other half — a job killed outright, taking pytest with it before any teardown
runs — no fixture can fix, and that is what the sweep is for.

## Known gap: battery voltage

The USB-C power bank exposes **no state-of-charge or voltage telemetry**, so the
robot cannot see its own battery in software. The only power signal available is
the Raspberry Pi firmware's `get_throttled` under-voltage bitfield, which
`system_monitor` already reports (a brown-out shows as `DEGRADED`). True battery
sensing needs a hardware change (a fuel-gauge / INA-class sensor on the power
rail) and is tracked as a follow-up — see the reliability follow-up task.

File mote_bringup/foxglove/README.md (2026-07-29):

# Foxglove layout

`mote.json` is the operator's layout: where the robot is, what it sees, and the
controls to drive it. Import it once per Foxglove install — **Layouts → Import
from file…** — then connect to `ws://<robot-id>:8765` over the tailnet. The
operator runbook is [`docs/fleet/README.md` §10](../../docs/fleet/README.md).

JSON has no comments, so the choices are recorded here.

## Panels

| Panel | Shows |
|---|---|
| **3D** | `/map` with the robot on it, `/scan_filtered`, `/plan`, TF, and the URDF model. Follows `base_footprint`, orthographic — a floor map read from above, not a 3D scene |
| **Image** | `/image_raw/compressed`. The compressed stream, never `/image_raw`: raw frames are ~100x the bytes over a WAN link |
| **Teleop** | drives the robot — see below |
| **Publish** | `/pause_navigation` — holds Nav2 off the wheels, see below |
| **Diagnostic summary** | `/diagnostics_agg` from the health monitor, per subsystem |

Costmaps, `/camera_obstacles`, `/detected_objects` and `/particle_cloud` ship
**present but hidden**: they are the topics you want one click away when
something looks wrong, and each is expensive enough that leaving it on would tax
every connection for the rare occasion it is needed. The bridge only serialises
what a panel has actually subscribed to, so a hidden topic costs nothing.

## Teleop

The panel publishes **`/cmd_vel_teleop`, not the controller's own topic**. It can
only emit `geometry_msgs/Twist`, while `DiffDriveController` consumes
`TwistStamped`, so `twist_relay` (started by `foxglove_launch.py`) adds the
header. The stamp is applied *on the robot*, which keeps the operator's clock out
of the safety path entirely.

Two numbers are load-bearing:

- **`publishRate: 10`.** The controller's `cmd_vel_timeout` is 0.5 s, so anything
  below 2 Hz makes the robot stutter — it halts between commands. Foxglove's
  panel default is 1 Hz, which is exactly that failure, so the rate is set here
  rather than left alone.
- **0.15 m/s and 0.6 rad/s**, roughly half of what `controllers.yaml` permits.
  Remote driving pays the link's latency before you see the consequence of a
  command, so the layout is deliberately slower than the robot can go. The
  controller clamps to its own maxima regardless, so editing these in the UI
  cannot exceed the robot's configured limits.

Releasing a button stops the robot, and so does losing the link: commands stop
arriving and `cmd_vel_timeout` halts the wheels. There is no remote e-stop — all
safety behaviour is local, as [`docs/design/fleet.md`](../../docs/design/fleet.md)
scopes it.

## Taking over from Nav2

**Teleop pre-empts an active goal.** The relay's output is the drive mux's
teleop input, which outranks Nav2's, so the first command you send takes the
wheels — no need to cancel the task first, and no two writers fighting over the
controller. See
[`mote_bringup/README.md` "Drive path"](../README.md#drive-path--who-gets-the-wheels)
for the arbitration.

**Releasing hands back, after a stop.** Nav2 stays suppressed for 1 s after your
last command while the controller halts the wheels at 0.5 s, so the robot always
comes to a stop before it starts driving itself again. It then resumes the same
goal — a takeover is an override, not a cancel.

**To stop it resuming**, use the **Publish** panel: it sends `std_msgs/Bool` on
`/pause_navigation`, and `{"data": true}` holds Nav2 off the wheels until you
send `{"data": false}`. Teleop still works while it is set. A goal held off the
wheels while the robot stands still fails Nav2's own progress checker after about
10 s and the task reports failed, which is usually what you wanted when you
reached for the pause.

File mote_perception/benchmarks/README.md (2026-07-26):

# Inference benchmarks

Latency/throughput for the off-board inference servers, so the dedicated
gaming-PC (NVIDIA/CUDA) tier can be compared against the earlier CPU and
ROCm-iGPU tiers. Numbers here are the **full socket round trip** measured with
`pixi run inference-bench` unless noted (that is what the robot actually pays —
compress → send → infer → receive), plus the server's own per-frame model time
where it isolates GPU-only cost.

Regenerate the CUDA numbers with, from the robot or a LAN machine:

```bash
pixi run inference-bench --host mote-gpu --image sample.jpg --frames 200 \
    --out mote_perception/benchmarks/depth_cuda_lan.json
pixi run inference-bench --service detect --host mote-gpu --labels "red box" \
    --frames 50 --out mote_perception/benchmarks/detect_cuda_lan.json
```

Commit the resulting `*.json` alongside this file and fill the tables below.

## Depth (Depth-Anything-V2-Small, 640×480)

| Tier | Machine | Device | ~ms/frame | ~fps | Source |
|---|---|---|---:|---:|---|
| CPU (idle) | Linux dev | CPU (physical-core threads) | ~330 | ~3 | #152, `depth_server.py` comment (measured with `depth_bag_eval.py`) |
| CPU (oversubscribed) | Linux dev | CPU (SMT threads) | ~460 | ~2 | #152, same |
| CPU (under load) | Linux dev / Pi-class | CPU while RViz+ROS+node run | ~1000–2000 | ~0.5–1 | #152 prose baseline |
| ROCm iGPU | Linux dev | Radeon 780M (gfx1103, fp32) | ~330, **flat under load** | ~3 | #152 — ties idle CPU, stays flat where CPU degrades |
| **CUDA (LAN)** | **container on the inference machine** | **NVIDIA (fp32)** | _measure_ | _measure_ | **`inference-bench` → `depth_cuda_lan.json`** |
| CUDA (fp16) | container | NVIDIA (`--fp16`) | _optional_ | _optional_ | optional, if fp16 is stable on the card |

Measure with the server warm: the first frame after an idle release includes the
model load (see `--idle-timeout` in `docs/inference-server.md`), which `--warmup`
already excludes by default.

The CUDA tier is expected to land well under the ROCm/CPU ~330 ms — a discrete
NVIDIA card runs this small ViT in tens of ms — so the depth rate is bounded by
the camera/publish rate, not the model. The point of the number is to *confirm*
that and to quantify the LAN overhead (round trip minus the server's reported
`served … in N ms`).

## Detect (OWLv2-base, 640×480)

OWLv2 is much heavier than depth and was CPU-only before this task; the
container's CUDA torch plus the `--device` support in `detect_server.py` let it
run on the GPU too. Measure once the inference machine is up:

| Tier | Machine | Device | ~ms/frame | ~fps | Source |
|---|---|---|---:|---:|---|
| CPU | Linux dev | CPU (all cores) | _prior_ | _prior_ | pre-CUDA baseline, if recorded |
| **CUDA (LAN)** | **container** | **NVIDIA** | _measure_ | _measure_ | **`inference-bench --service detect` → `detect_cuda_lan.json`** |

Detection is a per-command burst (the task layer asks for a label, not a stream),
so its latency matters for fetch responsiveness, not sustained fps.

## End-to-end (robot → server → `/camera_obstacles`)

The socket round trip above is the dominant term, but the full pipeline also
includes JPEG capture on the Pi, lidar rescale, back-projection, and publish. To
capture the whole leg over the real LAN, with the robot running `pixi run
perception` pointed at the gaming PC:

- read the depth node's cloud publish rate on `/camera_obstacles`
  (`ros2 topic hz /camera_obstacles`), and
- compare against `inference-bench`'s server round trip to attribute the rest to
  on-robot processing.

Record the observed `/camera_obstacles` Hz and the `inference-bench` summary here
once measured on hardware.

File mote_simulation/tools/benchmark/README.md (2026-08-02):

# Sim benchmark harness

Runs scripted nav missions in the headless Gazebo sim and scores them against
**Gazebo ground truth**, so Nav2 / SLAM / localization config changes can be
*proven* with numbers instead of eyeballed in RViz. This is the runner the
[parameter-sweep tool](sweep/README.md) (`pixi run bench-sweep`) and the IMU
study (`design/research/imu_fusion_study.md`) build on; the metric maths lives
in a ROS-free module (`metrics.py`) so an offline bag-replay scorer can reuse it
unchanged.

## Usage

```bash
pixi run bench                                          # default: mote_world + hospital_world, 2 trials each
pixi run bench -- --worlds mote_world.sdf --trials 3    # one world, 3 trials
pixi run bench -- --worlds mote_world.sdf,office_world.sdf,hospital_world.sdf
```

Needs a GPU workstation (headless gz-sim). Only one gz instance runs at a time,
so worlds and trials run strictly sequentially — a full default run is several
minutes. Each trial launches the *real* `sim_launch.py mode:=nav` (the same
mission `pixi run sim-nav` runs), so the benchmark exercises the production
launch files against each world's committed sim Site map.

Useful flags (`pixi run bench -- --help`):

| flag | default | meaning |
| --- | --- | --- |
| `--worlds` | `mote_world.sdf,hospital_world.sdf` | comma-separated world files |
| `--trials` | `2` | trials per world (repeat to measure variance) |
| `--order` | `pickup,dropoff,home` | zone names cycled as NavigateToPose goals |
| `--goal-timeout` | `120` | sim seconds allowed per goal |
| `--wheel-mu` | `1.0` | drive-wheel friction; `<1` induces wheel slip |
| `--slip` | off | shorthand for `--wheel-mu 0.4` (slip condition) |
| `--out` | `benchmark_results/` | output root (git-ignored) |

A caveat on `--slip`: lowering wheel friction does make the velocity-controlled
wheels slip, but kinematic_icp re-registers against the scan every frame, so the
slip is largely **absent from the resulting pose**. Do not expect it to degrade
the localization or odometry ATE much — see
`design/research/imu_fusion_study.md`. It is still useful for exercising code
that reads the *disagreement* between wheel odom and the scan-matched pose,
which slip does affect.

## What it measures

Per trial, gated on sim `/clock` (invariant to real-time factor):

- **localization error** — ATE (RMS/mean/median/max) of the estimated
  `map`→`base_footprint` pose vs. the bridged true pose, after a rigid SE(2)
  alignment (the SLAM `map` frame and the Gazebo world frame share no fixed
  transform, so alignment is required before differencing). Raw pre-alignment
  RMSE is also reported.
- **odometry error** — a second ATE of the **`odom`→`base_footprint`
  dead-reckoning** pose vs. truth, with no map correction (`odometry.*`). AMCL's
  map correction can mask an odometry change in the localization ATE above; this
  isolates odometry quality (kinematic_icp tuning, param sweeps) from the map
  correction that would otherwise hide a change in it.
- **goal success rate & time-to-goal** — over the scripted goal cycle.
- **clearance** — nearest obstacle from `/scan_filtered`: min, 5th-percentile,
  mean, and the fraction of time spent inside 0.15/0.20/0.30 m bands.
- **Nav2 recoveries / aborts** — distinct recovery goals seen on the
  behavior-server action status topics (`spin`, `backup`, `drive_on_heading`,
  `wait`), plus aborted NavigateToPose goals.
- **motion smoothness** — RMS linear/angular jerk from `cmd_vel` and the number
  of forward/backward direction reversals.
- **map quality** (`map_quality`, when a finished grid is scored) — crispness
  and coverage proxies, plus **angular structure** from
  `mote_bringup.map_cleanup.angular_stats`: `angular_support_deg` and the
  wall-direction / orthogonal-frame tables. Imported lazily, so this module
  keeps its numpy-only, ROS-free contract and still scores where `mote_bringup`
  is not on the path — the angular keys are simply absent then.

  Angular structure is a **tear detector, not a quality ranking**, and the sim
  does not rank on it: with Gazebo's true pose the sim reports ATE, which is a
  strictly better answer. It earns its place in the **bag-replay** harness,
  where there is no ground truth — and specifically where the trajectory does
  not close, so loop drift is unavailable too. See `../bag_replay/README.md` for
  how to read it and what it cannot decide.

## Ground truth

The robot's true pose is bridged out of Gazebo with `ros_gz_bridge`
(`/model/mote/pose`, `gz.msgs.Pose` → `geometry_msgs/PoseStamped`), published by a
`PosePublisher` system plugin on the robot model (added to the URDF under the
`use_sim` guard, so the real-robot description is unchanged). `SceneBroadcaster`'s
`/world/<world>/pose/info` was the obvious source but loses model frame names
through the bridge; `PosePublisher` populates them. The bridge is started and torn
down by the harness, so the mission under test is unperturbed.

## Graph isolation

A benchmark is only meaningful if the graph it measures is its own, so each run
is fenced off twice:

- **Off this machine.** The `sim` pixi environment exports
  `ROS_AUTOMATIC_DISCOVERY_RANGE=LOCALHOST`, so every sim/benchmark participant
  confines DDS discovery to this host. A robot or another workstation on the LAN
  can neither be discovered by nor discover a benchmark run.
- **From other runs on this machine.** `bench.py` claims a free `ROS_DOMAIN_ID`
  per invocation (probing which CycloneDDS discovery ports are already bound)
  plus a matching `GZ_PARTITION` for Gazebo's own transport, and records both in
  `run.json` / `report.md`. An inherited `ROS_DOMAIN_ID` is respected instead —
  that is how [the sweep](sweep/README.md) pins all of its sets to one domain.
  The picker is [`../sim_domain.py`](../sim_domain.py), shared with the smoke
  test and `map_world.sh` so every sim entry point isolates the same way.

Teardown is scoped to match. Each launch runs in its own session, so killing
that session reaps stragglers under any node name without reaching another run;
the last-resort `pkill` for an escaped `gz sim` is scoped to this repo's world
path. Two benchmarks — or a benchmark and a smoke test — can therefore run at
once, in the same worktree or different ones.

To watch a running sim in RViz, use `pixi run rviz-sim` — a default-range RViz
cannot see a `LOCALHOST`-only participant (the reverse direction does work).

## Outputs

```
benchmark_results/<UTC timestamp>/
  report.md                     # human-readable per-world tables (mean/std/min/max/CV)
  run.json                      # full run: provenance + every trial's metrics + aggregate
  <world>/trial_<i>/
    series.json                 # raw recorded samples — re-scorable offline via metrics.py
    metrics.json                # this trial's summary
    sim.log, bridge.log         # launch logs (for post-mortem)
```

`report.md` reports the **coefficient of variation (CV = std/mean)** for each
metric so run-to-run variance is explicit when comparing two configs. Provenance
(git commit, world, map revision, nav2_params path, timestamp) is recorded in
both `run.json` and the report so two runs are comparable.

## Observed baseline & variance

From `pixi run bench -- --worlds mote_world.sdf,hospital_world.sdf --trials 2`
(commit `f177473`, sim maps as committed). Two trials per world; the point is
that a fixed config is *reproducible* enough to compare against:

| world | goals ok | ATE rmse (mean ± std) | ATE CV | time-to-goal CV | min clearance |
| --- | --- | --- | --- | --- | --- |
| mote_world | 3/3, 3/3 | 0.068 ± 0.007 m | 10% | 0.8% | 0.95 m |
| hospital_world | 2/3, 1/3 | 0.085 ± 0.004 m | 4% | 4.9% | 0.34 m |

Localization ATE is stable across trials in **both** worlds (CV ≤ 10%), so a
config change that moves ATE by more than a few cm is a real signal, not noise.
Goal-success is the noisier axis: mote completes every goal, while hospital's
long (~30 m) legs bump the default 120 s `--goal-timeout` non-deterministically
(2/3 then 1/3) — localization is fine there, the legs just need more time. For a
fair hospital success rate, raise the cap, e.g.
`--worlds hospital_world.sdf --goal-timeout 300`.

A settle period (`--settle`, default 8 s) before the first goal is load-bearing:
driving the instant TF appears, before AMCL and the costmaps converge, makes the
robot mislocalize and fail every goal. 8 s is enough for these worlds.

## Layout

| file | role | ROS? |
| --- | --- | --- |
| `bench.py` | orchestrator: launch sim + GT bridge, gate readiness, loop trials, tear down, aggregate, write report | processes only |
| `record.py` | one-trial ROS client: drive goals, record series, write `series.json` + `metrics.json` | rclpy |
| `metrics.py` | ATE / goals / clearance / smoothness / aggregation | **no** (numpy only) |
| `report.py` | aggregate trials → markdown + run JSON | no |

Reusing the metrics offline is just `metrics.summarize(series_dict)` on a
`series.json` (or any producer of the same shapes).

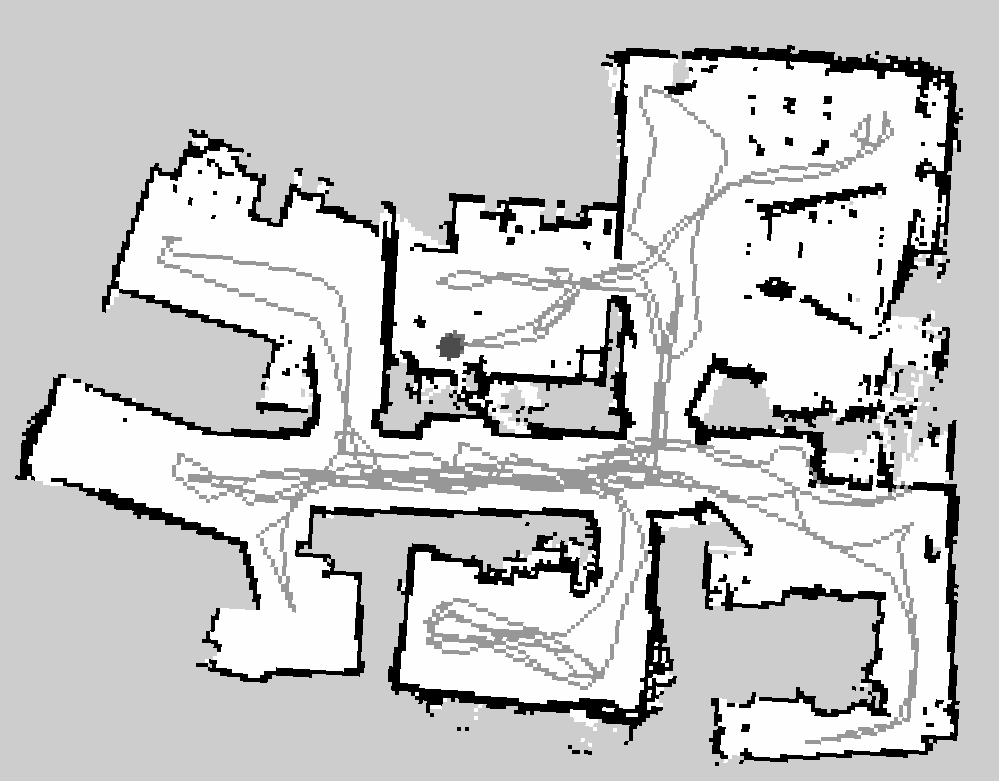
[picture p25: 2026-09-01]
docs/tuning/2026-09-01-alignment-residual/unaligned-squared.png

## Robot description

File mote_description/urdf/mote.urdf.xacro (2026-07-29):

<?xml version="1.0"?>
<robot name="mote" xmlns:xacro="http://www.ros.org/wiki/xacro">

  <xacro:property name="cfg" value="${xacro.load_yaml('$(find mote_description)/config/robot.yaml')}"/>

  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
  <xacro:arg name="use_sim" default="false"/>
  <xacro:arg name="sim_controllers_file" default=""/>
  <xacro:property name="use_sim" value="$(arg use_sim)"/>

  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
  <xacro:arg name="arm" default="true"/>
  <xacro:property name="arm" value="$(arg arm)"/>

  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
  <xacro:arg name="wheel_mu" default="1.0"/>
  <xacro:property name="wheel_mu" value="$(arg wheel_mu)"/>


  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
  <xacro:property name="base_plate_top_height" value="0.016"/>
  <xacro:property name="lidar_ground_height" value="0.054"/>
  <xacro:property name="cam_ground_height" value="0.094"/>

  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
  <xacro:property name="chassis_radius" value="0.115"/>
  <xacro:property name="plate_thickness" value="0.006"/>
  <xacro:property name="plate_gap" value="0.050"/>
  <xacro:property name="plate_mass" value="0.01"/>  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
  <xacro:property name="wheel_radius" value="${cfg['wheel_radius']}"/>
  <xacro:property name="wheel_width" value="0.006"/>
  <xacro:property name="wheel_mass" value="0.05"/>  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
  <xacro:property name="wheel_separation" value="${cfg['wheel_separation']}"/>
  <xacro:property name="axle_z" value="0.0095"/>

  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
  <xacro:property name="caster_radius" value="0.016"/>  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
  <xacro:property name="caster_mass" value="0.01"/>   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
  <xacro:property name="caster_x" value="0.100"/>  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
  <xacro:property name="caster_z" value="${caster_radius - (wheel_radius - axle_z)}"/>

  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
  <xacro:property name="lidar_x" value="0.080"/>
  <xacro:property name="lidar_z" value="0.038"/>

  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
  <xacro:property name="cam_x" value="0.110"/>
  <xacro:property name="cam_z" value="0.021"/>

  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

  <xacro:property name="base_plate_z" value="${-axle_z}"/>
  <xacro:property name="top_plate_z" value="${plate_gap + plate_thickness}"/>

  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

  <link name="base_footprint"/>

  <link name="base_link"/>

  <joint name="base_footprint_joint" type="fixed">
    <parent link="base_footprint"/>
    <child link="base_link"/>
    <origin xyz="0 0 ${wheel_radius}" rpy="0 0 0"/>
  </joint>

  <link name="base_plate_link">
    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
    <inertial>
      <mass value="${plate_mass}"/>
      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
    </inertial>
  </link>

  <joint name="base_plate_joint" type="fixed">
    <parent link="base_link"/>
    <child link="base_plate_link"/>
    <origin xyz="0 0 ${base_plate_z}" rpy="0 0 0"/>
  </joint>

  <link name="top_plate_link">
    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
    <inertial>
      <mass value="${plate_mass}"/>
      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
    </inertial>
  </link>

  <joint name="top_plate_joint" type="fixed">
    <parent link="base_plate_link"/>
    <child link="top_plate_link"/>
    <origin xyz="0 0 ${top_plate_z}" rpy="0 0 0"/>
  </joint>

  <xacro:macro name="wheel" params="name y_reflect">
    <link name="${name}_wheel_link">
      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
      <inertial>
        <mass value="${wheel_mass}"/>
        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
      </inertial>
    </link>

    <joint name="${name}_wheel_joint" type="continuous">
      <parent link="base_link"/>
      <child link="${name}_wheel_link"/>
      <origin xyz="0 ${y_reflect * wheel_separation / 2} 0" rpy="0 0 0"/>
      <axis xyz="0 1 0"/>
    </joint>
  </xacro:macro>

  <xacro:wheel name="left" y_reflect=" 1"/>
  <xacro:wheel name="right" y_reflect="-1"/>

  <link name="caster_link">
    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
    <inertial>
      <mass value="${caster_mass}"/>
      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
    </inertial>
  </link>

  <joint name="caster_joint" type="fixed">
    <parent link="base_plate_link"/>
    <child link="caster_link"/>
    <origin xyz="${caster_x} 0 ${caster_z}" rpy="0 0 0"/>
  </joint>

  <link name="lidar_link">
    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
  </link>

  <joint name="lidar_joint" type="fixed">
    <parent link="base_plate_link"/>
    <child link="lidar_link"/>
    <origin xyz="${lidar_x} 0 ${lidar_z}" rpy="0 0 ${pi/2}"/>
  </joint>

  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
  <link name="lidar_scan_link"/>
  <joint name="lidar_scan_joint" type="fixed">
    <parent link="lidar_link"/>
    <child link="lidar_scan_link"/>
    <origin xyz="0 0 0" rpy="0 0 ${pi}"/>
  </joint>

  <link name="camera_link">
    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
  </link>

  <joint name="camera_joint" type="fixed">
    <parent link="top_plate_link"/>
    <child link="camera_link"/>
    <origin xyz="${cam_x} 0 ${cam_z}" rpy="0 0 0"/>
  </joint>

  <link name="camera_optical_link"/>
  <joint name="camera_optical_joint" type="fixed">
    <parent link="camera_link"/>
    <child link="camera_optical_link"/>
    <origin xyz="0 0 0" rpy="${-pi/2} 0 ${-pi/2}"/>
  </joint>

  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
  <xacro:if value="${arm}">
    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

    <xacro:macro name="arm_link" params="name length radius:=0.018">
      <link name="${name}">
        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
      </link>
    </xacro:macro>

    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
    <link name="arm_base_link">
      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
    </link>
    <joint name="arm_mount_joint" type="fixed">
      <parent link="top_plate_link"/>
      <child link="arm_base_link"/>
      <origin xyz="0.0 0 0.015" rpy="0 0 0"/>
    </joint>

    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
    <xacro:arm_link name="shoulder_pan_link" length="0.04"/>
    <joint name="shoulder_pan" type="revolute">
      <parent link="arm_base_link"/>
      <child link="shoulder_pan_link"/>
      <origin xyz="0 0 0.015" rpy="0 0 0"/>
      <axis xyz="0 0 1"/>
      <limit lower="-3.14" upper="3.14" effort="10" velocity="3.0"/>
    </joint>

    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
    <xacro:arm_link name="shoulder_lift_link" length="0.116"/>
    <joint name="shoulder_lift" type="revolute">
      <parent link="shoulder_pan_link"/>
      <child link="shoulder_lift_link"/>
      <origin xyz="0 0 0.04" rpy="0 0 0"/>
      <axis xyz="0 1 0"/>
      <limit lower="-3.14" upper="3.14" effort="10" velocity="3.0"/>
    </joint>

    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
    <xacro:arm_link name="elbow_flex_link" length="0.135"/>
    <joint name="elbow_flex" type="revolute">
      <parent link="shoulder_lift_link"/>
      <child link="elbow_flex_link"/>
      <origin xyz="0 0 0.116" rpy="0 0 0"/>
      <axis xyz="0 1 0"/>
      <limit lower="-3.14" upper="3.14" effort="10" velocity="3.0"/>
    </joint>

    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
    <xacro:arm_link name="wrist_flex_link" length="0.05"/>
    <joint name="wrist_flex" type="revolute">
      <parent link="elbow_flex_link"/>
      <child link="wrist_flex_link"/>
      <origin xyz="0 0 0.135" rpy="0 0 0"/>
      <axis xyz="0 1 0"/>
      <limit lower="-3.14" upper="3.14" effort="10" velocity="3.0"/>
    </joint>

    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
    <xacro:arm_link name="wrist_roll_link" length="0.04"/>
    <joint name="wrist_roll" type="revolute">
      <parent link="wrist_flex_link"/>
      <child link="wrist_roll_link"/>
      <origin xyz="0 0 0.05" rpy="0 0 0"/>
      <axis xyz="0 0 1"/>
      <limit lower="-3.14" upper="3.14" effort="10" velocity="3.0"/>
    </joint>

    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
    <xacro:arm_link name="gripper_link" length="0.05" radius="0.012"/>
    <joint name="gripper" type="revolute">
      <parent link="wrist_roll_link"/>
      <child link="gripper_link"/>
      <origin xyz="0.0 0 0.04" rpy="0 0 0"/>
      <axis xyz="0 1 0"/>
      <limit lower="-0.2" upper="1.7" effort="10" velocity="3.0"/>
    </joint>
  </xacro:if>

  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
  <xacro:arg name="arm_config" default=""/>
  <xacro:property name="arm_config_file" value="$(arg arm_config)"/>
  <xacro:property name="arm_cfg" value="${xacro.load_yaml(arm_config_file) if arm_config_file else cfg['arm']}"/>

  <xacro:property name="arm_on_wheel_bus" value="${arm and arm_cfg['port'] == cfg['servos']['port']}"/>

  <xacro:macro name="arm_control_joint" params="spec">
    <joint name="${spec['name']}">
      <param name="id">${spec['id']}</param>
      <param name="min">${spec['min']}</param>
      <param name="max">${spec['max']}</param>
      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
      <param name="zero">${spec['zero']}</param>
      <param name="invert">${'true' if 'invert' in spec and spec['invert'] else 'false'}</param>
      <command_interface name="position"/>
      <state_interface name="position"/>
    </joint>
  </xacro:macro>
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

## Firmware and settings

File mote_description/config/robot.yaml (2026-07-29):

# Single source of truth for robot configuration.
# Consumed by mote.urdf.xacro (via xacro.load_yaml) and mote_launch.py (via yaml.safe_load).

# Physical geometry — used by the URDF for visualization and by diff_drive_controller for odometry
wheel_radius: 0.0325
wheel_separation: 0.22

# Maximum wheel surface speed the servos sustain at the 5V supply — the hard
# ceiling measured from recorded odometry, not a datasheet value. Consumed by
# the Nav2 WheelSpeedLimit critic (injected via nav2_launch.py) to keep
# commanded (v, omega) within what the differential drive can actually deliver.
max_wheel_speed: 0.218

# Drive servo bus
servos:
  port: /dev/mote_servos
  baud_rate: 1000000
  left_id: 7
  right_id: 9
  velocity_scale: 674.1  # rad/s to servo speed units; measure with `ros2 run mote_hardware velocity_cal`
  acceleration: 0        # 0 = maximum acceleration

# SO-101 follower arm (Feetech STS-class servos on their own serial bus).
# Consumed by mote_arm (driver, jog CLI, arm_check) and by the arm section of
# mote.urdf.xacro. There is no leader arm — this is the follower only.
#
# CALIBRATION STATUS: the min/max and `zero` below are uncalibrated defaults.
# Calibration is per-robot and does not edit this file — `pixi run arm-calibrate`
# (mote_arm/BENCH.md step 3) saves to `$MOTE_HOME/arm.yaml`, which overrides
# these three fields per joint at load time. See DEFAULTS ONLY below.
#
# WIRING: the arm SHARES the drive-wheel bus (verified on the robot: IDs 1-6
# for the arm, 7/9 for the wheels, all on /dev/mote_servos). Consequences:
#   * arm IDs must never collide with the wheel IDs — rejected at load time by
#     mote_arm.config and again by MoteHardware::on_init;
#   * only one process may open this port, and that process is the
#     controller_manager: MoteHardware drives the arm's position interfaces
#     alongside the wheels' velocity ones, so the arm can move during a mission.
#     The joint entries below are read by mote.urdf.xacro into <ros2_control>
#     joint <param>s, which is how each servo's limits reach the hardware;
#   * the bench tools that still open the bus directly (arm-check, arm-gains)
#     need the control stack stopped first.
arm:
  port: /dev/mote_servos
  baud_rate: 1000000
  moving_speed: 500      # jog move speed cap, servo steps/s (gentle)
  moving_acc: 20         # 0-254, units of 100 steps/s^2
  # Position-loop gains, held in each servo's EEPROM. Recorded here so they
  # survive a servo swap and stay in one place with the rest of the arm config;
  # apply and verify them with `pixi run arm-gains apply`.
  #
  # The arm shipped with kp=16, which leaves a permanent steady-state error
  # under load: the servo settles where kp*error balances the holding torque and
  # ki=0 never integrates it away. `pixi run arm-gains sweep` measured it on
  # elbow_flex, -0.200 rad from rest (repeated; both runs agreed to 1-2 counts):
  #
  #   kp    16     32     64    128
  #   err  0.068  0.031  0.014  0.008 rad
  #   load  188    168    144    144  of 1000
  #
  # Error falls 8.2x for an 8x gain rise at a load nowhere near the 1000 that
  # torque saturation would pin it to: droop, and the 5.1-5.2 V supply is not
  # what limits it. 64 is chosen over the best-scoring 128 deliberately — it
  # takes half the remaining error and still leaves a measured 2x margin below
  # the highest gain tested, which matters because every regime that punishes a
  # stiff loop (a payload, a collision, hand-guiding) is untested, and this arm
  # exists to touch things. ki stays 0: ki=8 closed the error to 0.001 rad but
  # stretched settling from 0.46 s to 2.12 s, which a 20 Hz streamed setpoint
  # never waits for. See mote_arm/README.md.
  gains:
    kp: 64
    kd: 32
    ki: 0
  # min/max are soft limits in radians about each joint's zero; `zero` is the
  # raw encoder count (0-4095) that reads 0 rad.
  #
  # `zero` is NOT the arm's rest pose. After calibration 0 rad is the middle of
  # each joint's travel; the rest pose is a taught pose called "home" in
  # ~/.mote/arm_poses.yaml. The two were both called "home" until 2026-07-28,
  # which is exactly why this key is now spelled `zero` (`home:` is still
  # accepted for an un-migrated file).
  #
  # Calibration is `pixi run arm-calibrate`: it sweeps every joint to its
  # mechanical stops, writes each servo's homing-offset register so the measured
  # mid-travel reads 2048, and saves the resulting zeros and limits to
  # `$MOTE_HOME/arm.yaml`. Centring matters — without it a joint whose travel
  # straddles the encoder's 0/4095 wrap cannot be described by any zero/limit
  # pair at all, and two of six joints on the first real arm did.
  #
  # A pose is stored as radians about its joint's `zero`, so moving a zero
  # changes which physical position each number names. `arm-calibrate` rewrites
  # the taught poses by exactly the shift it applied, so they keep pointing
  # where they did; only a pose left outside the new limits needs a decision.
  #
  # DEFAULTS ONLY — a calibrated robot overrides `zero`/`min`/`max` per joint
  # from `$MOTE_HOME/arm.yaml` (written by `pixi run arm-calibrate`), because
  # those are measurements of one physical arm and every arm's differ. What
  # stays here is the design: ids, names, direction, gains.
  #
  # These particular numbers are the old pose-envelope output (`arm-pose
  # limits`) and describe where one arm had *been*, not where it can go — the
  # parked pose it was measured from sits within ~20 counts of a hard stop on
  # most joints, and shoulder_pan's [0.010, 0.229] does not contain its own
  # zero. Treat them as a conservative placeholder until a robot calibrates.
  joints:
    - {name: shoulder_pan,  id: 1, min:  0.010, max: 0.229, zero: 3013, invert: false}
    - {name: shoulder_lift, id: 2, min: -0.102, max: 0.100, zero: 1483, invert: false}
    - {name: elbow_flex,    id: 3, min: -3.291, max: 0.103, zero: 2931, invert: false}
    - {name: wrist_flex,    id: 4, min: -3.226, max: 0.097, zero: 2767, invert: false}
    - {name: wrist_roll,    id: 5, min: -0.098, max: 0.102, zero:  731, invert: false}
    - {name: gripper,       id: 6, min: -0.102, max: 0.098, zero: 2056, invert: false}

# Sensors
lidar:
  port: /dev/mote_lidar
  baud_rate: 460800
  # Simulated lidar parameters (RPLIDAR C1 datasheet values) — used only by
  # the use_sim branch of the URDF; the real driver gets these from the device
  sim:
    update_rate: 10.0
    samples: 720
    range_min: 0.05
    range_max: 12.0

camera:
  device: /dev/mote_camera
  image_size: [640, 480]
  # Default fallback intrinsics; a per-robot ~/.mote/camera_calibration.yaml overrides it.
  default_info_url: package://mote_perception/config/camera_info.default.yaml
  # Simulated camera parameters — used only by the use_sim branch of the URDF;
  # the real driver gets its intrinsics from default_info_url instead. The FOV
  # matches the calibrated real lens (fx ~469.6 over 640 px -> ~68.6deg) so sim
  # and real geometry stay consistent.
  sim:
    update_rate: 30.0
    horizontal_fov: 1.20
    width: 640
    height: 480
    near: 0.05
    far: 20.0

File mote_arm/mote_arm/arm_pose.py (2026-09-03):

"""Teach and replay named arm poses.

A client of the ros2_control stack (reads ``/joint_states``, commands
``arm_controller``), so it never opens the serial bus and cannot contend with
the wheels — see ``mote_arm/control.py``.

    pixi run arm-pose save <name>   # capture the arm's current pose
    pixi run arm-pose list          # show taught poses (and current offset)
    pixi run arm-pose go <name>     # move to a taught pose
    pixi run arm-pose delete <name>

``save`` moves nothing — pose the limp arm by hand, then capture it. It stores
each joint clamped into its soft band and says which ones it held there: posing
by hand means posing against the mechanical stops, and the soft limits sit a
margin inside those, so a raw capture is routinely a fraction outside the band
and could never be replayed. ``go`` is the only command that moves the arm, and
it leaves the arm *holding* the pose it reached (deactivate ``arm_controller``,
or press SPACE in ``arm-teleop``, to make it limp again): it reports the
distance each joint will travel and then moves. There is no confirmation: the
move is bounded by ``--speed`` and supervised by ``--max-lag``, the destination
is a pose the operator taught and `save` already clamped into the soft limits,
and a prompt on every bench move is a keypress that buys none of that. Goals are
clamped to the soft limits here *and* in the driver.

There is no ceiling on how far a `go` may move. Distance is not what makes a
move risky once setpoints are streamed: the arm advances at ``--speed``
whatever the distance, so a long move is a slow move rather than a violent one,
and ``--max-lag`` stops it if the arm falls behind. A distance limit was a proxy
for the lurch that streaming removed, and with real calibrated joints it refused
the ordinary case — teach a pose, let go, watch the limp arm fall to rest,
replay. ``episode-replay`` keeps one for a different job: there a long approach
means the arm is not where the recording starts, so the replay will not
reproduce.

The arm is limp whenever no controller holds it, so it falls to rest the moment
you let go of it. A `go` straight after a `save` therefore starts from the rest
position and not from the pose just taught, and the travel it reports is real.

``go`` streams setpoints at a fixed rate rather than commanding the destination
in one jump, so the arm moves continuously at ``--speed`` instead of lurching,
and it stops if the arm falls behind its setpoint by more than ``--max-lag``.
The lag is measured against ``/joint_states``, which the hardware refreshes one
arm joint per control cycle (~8 Hz per joint) to stay inside the bus budget it
shares with the wheels, so lag is detected within a few setpoints rather than
instantly.
"""

from __future__ import annotations

import argparse
import sys
import threading
import time

import rclpy
from rclpy.node import Node
from sensor_msgs.msg import JointState

from mote_arm import cli, config, poses
from mote_arm.calibrate import DEFAULT_MARGIN
from mote_arm.control import ArmControl
from mote_arm.motion import LagSupervisor, lag_of


class PoseClient(Node):
    def __init__(self):
        super().__init__("arm_pose")
        self.cfg = config.load()
        self._measured: dict[str, float] = {}
        self._lock = threading.Lock()
        self.create_subscription(JointState, "joint_states", self._on_states, 10)
        self.arm = ArmControl(self)

    def _on_states(self, msg: JointState) -> None:
        arm_names = set(self.cfg.names)
        with self._lock:
            for name, pos in zip(msg.name, msg.position):
                if name in arm_names:
                    self._measured[name] = pos

    def current(self) -> dict[str, float]:
        with self._lock:
            return dict(self._measured)

    def wait_for_states(self, timeout: float = 5.0) -> bool:
        deadline = time.time() + timeout
        while time.time() < deadline:
            if len(self.current()) == len(self.cfg.names):
                return True
            time.sleep(0.05)
        return False

    def send(self, joints: dict[str, float], seconds: float) -> bool:
        """Command one streamed setpoint, taking hold of the arm if it is limp."""
        return self.arm.send(joints, seconds)


def _require_states(node: PoseClient) -> dict[str, float]:
    if not node.wait_for_states():
        raise SystemExit(
            "no /joint_states for all arm joints — is a stack that owns the "
            "servo bus running (`pixi run arm`, or `pixi run robot`)?"
        )
    return node.current()


def _cmd_save(node: PoseClient, args) -> None:
    """Capture the arm's pose, clamped into the band it can actually be sent to.

    Posing by hand means posing a limp arm against its mechanical stops, and the
    soft limits sit a margin (0.05 rad) inside those, so a captured position is
    routinely a fraction past the band. Stored raw, that pose can never be
    reached: every `go` clamps it and says so, which is a warning the operator
    receives minutes later and cannot act on. Stored clamped, it is reachable by
    construction and differs from what was posed by at most the margin.

    A joint further out than the margin is a different matter -- it means the
    arm and arm.yaml disagree about where that joint's limits are -- so it is
    called out separately rather than folded into the same quiet clamp.
    """
    current = _require_states(node)
    clamped: dict[str, float] = {}
    held: dict[str, float] = {}
    suspect: list[str] = []
    for name, value in current.items():
        try:
            joint = node.cfg.joint(name)
        except KeyError:
            clamped[name] = value
            continue
        clamped[name] = joint.clamp_rad(value)
        if clamped[name] != value:
            held[name] = value
            # DEFAULT_MARGIN rather than the joint's own: arm.yaml records the
            # margin per joint but JointSpec does not carry it, and the two
            # differ only if someone passed --margin to arm-setup calibrate.
            if abs(clamped[name] - value) > DEFAULT_MARGIN:
                suspect.append(name)

    path = poses.save_pose(args.name, clamped)
    print(f"saved pose {args.name!r} to {path}")
    for name in node.cfg.names:
        note = (
            f"  <- held at the soft limit, from {held[name]:+.4f}"
            if name in held
            else ""
        )
        print(f"  {name:<14} {clamped[name]:+.4f} rad{note}")
    if held:
        print(
            f"\n{len(held)} joint(s) were posed past their soft limits and are "
            "stored at the limit, so this pose is reachable as saved. Posing a "
            "limp arm against its stops does this: the soft limits sit a margin "
            "inside them."
        )
    if suspect:
        print(
            f"\n{', '.join(suspect)}: further out than the calibration margin, "
            "so the arm and $MOTE_HOME/arm.yaml disagree about this joint's "
            "limits. `pixi run arm-setup calibrate` re-measures them."
        )


def _cmd_list(node: PoseClient, args) -> None:
    taught = poses.load_poses()
    if not taught:
        print(f"no poses taught yet (would live in {poses.poses_path()})")
        return
    current = node.current() if node.wait_for_states(timeout=2.0) else {}
    for name, joints in sorted(taught.items()):
        print(f"\n{name}:")
        for joint, value in joints.items():
            if joint in current:
                delta = current[joint] - value
                print(f"  {joint:<14} {value:+.4f} rad   (now {delta:+.4f} away)")
            else:
                print(f"  {joint:<14} {value:+.4f} rad")


def _cmd_delete(node: PoseClient, args) -> None:
    if poses.delete_pose(args.name):
        print(f"deleted pose {args.name!r}")
    else:
        raise SystemExit(f"no pose named {args.name!r}")


def _cmd_limits(node: PoseClient, args) -> None:
    """Emit robot.yaml soft limits spanning every taught pose."""
    taught = poses.load_poses()
    if not taught:
        raise SystemExit("no poses taught yet — capture some with `arm-pose save`")

    band = poses.envelope(taught, margin=args.margin)
    print(
        f"# soft limits spanning {len(taught)} taught pose(s): "
        f"{', '.join(sorted(taught))}"
    )
    print(
        f"# margin {args.margin:+.3f} rad; joints with no taught position keep "
        "their current limits"
    )
    print("  joints:")
    for joint in node.cfg.joints:
        if joint.name in band:
            lo, hi = band[joint.name]
            note = ""
        else:
            lo, hi = joint.min_rad, joint.max_rad
            note = "  # unchanged (not in any taught pose)"
        print(
            f"    - {{name: {joint.name + ',':<16} id: {joint.id}, "
            f"min: {lo:>7.3f}, max: {hi:>7.3f}, "
            f"zero: {joint.zero_counts:>4}, invert: {str(joint.invert).lower()}}}{note}"
        )

    print("\n# sanity check against the taught poses:")
    for pose_name, joints in sorted(taught.items()):
        outside = [
            n
            for n, v in joints.items()
            if n in band and not (band[n][0] <= v <= band[n][1])
        ]
        status = "OK" if not outside else f"OUTSIDE for {outside}"
        print(f"#   {pose_name}: {status}")


def _cmd_go(node: PoseClient, args) -> None:
    taught = poses.load_poses()
    if args.name not in taught:
        raise SystemExit(
            f"no pose named {args.name!r} (have: {sorted(taught) or 'none'})"
        )
    target = taught[args.name]
    current = _require_states(node)

    goals: dict[str, float] = {}
    print(f"move to pose {args.name!r}:")
    largest = 0.0
    for joint_name, value in target.items():
        try:
            joint = node.cfg.joint(joint_name)
        except KeyError:
            print(f"  {joint_name:<14} SKIPPED (not an arm joint any more)")
            continue
        clamped = joint.clamp_rad(value)
        now = current.get(joint_name)
        travel = abs(clamped - now) if now is not None else float("nan")
        largest = max(largest, travel if travel == travel else 0.0)
        note = "  (CLAMPED)" if clamped != value else ""
        print(
            f"  {joint_name:<14} {now:+.4f} -> {clamped:+.4f} rad "
            f"(travel {travel:.4f}){note}"
        )
        goals[joint_name] = clamped

    print(f"largest single-joint travel: {largest:.4f} rad")

    _stream(node, current, goals, args)

    final = node.current()
    print("\nfinal pose:")
    for name in node.cfg.names:
        if name in goals:
            err = final.get(name, float("nan")) - goals[name]
            print(
                f"  {name:<14} {final.get(name, float('nan')):+.4f} rad "
                f"(target {goals[name]:+.4f}, err {err:+.4f})"
            )


SETPOINT_RATE_HZ = 20.0


def _stream(node: PoseClient, start: dict, goals: dict, args) -> None:
    """Walk to ``goals`` by streaming setpoints at a fixed rate.

    Waiting for each waypoint to *settle* before issuing the next makes the arm
    move in visible stop-start hops. Streaming a fresh setpoint every tick keeps
    the servo's target always just ahead of where it is, so the motion is
    continuous and its speed is set by ``--speed`` rather than by how quickly
    each hop happens to converge.

    Supervision is by *lag*: how far the arm trails the setpoint it was given.
    Lag that stays above ``--max-lag`` means the arm is no longer keeping up —
    the same stall condition as before, detected without pausing.
    """
    period = 1.0 / SETPOINT_RATE_HZ
    stream = poses.interpolate(start, goals, max(1e-4, args.speed / SETPOINT_RATE_HZ))
    print(
        f"\nstreaming {len(stream)} setpoints at {SETPOINT_RATE_HZ:.0f} Hz "
        f"({args.speed:.2f} rad/s), stopping if lag exceeds {args.max_lag:.2f} rad"
    )

    supervisor = LagSupervisor(args.max_lag, args.stall_time)
    report_every = max(1, len(stream) // 8)
    for i, setpoint in enumerate(stream, 1):
        node.send(setpoint, period)
        time.sleep(period)
        now = node.current()
        lag = lag_of(setpoint, now)
        if not supervisor.update(lag, period):
            print(
                f"\nSTOPPED at setpoint {i}/{len(stream)}: the arm trailed by "
                f"{lag:.3f} rad for {args.stall_time:.1f}s. Holding here rather "
                "than driving against a load it is not overcoming."
            )
            return
        if i % report_every == 0 or i == len(stream):
            print(
                f"  {i:>4}/{len(stream)}  lag {lag:.4f} rad   "
                + " ".join(
                    f"{n.split('_')[0]}={now.get(n, float('nan')):+.3f}"
                    for n in sorted(setpoint)
                )
            )

    # The stream ends exactly on target; give the servo a moment to close the
    # remaining proportional droop before reporting the final pose.
    deadline = time.time() + args.timeout
    while time.time() < deadline:
        time.sleep(0.1)
        now = node.current()
        err = max((abs(now.get(n, goals[n]) - goals[n]) for n in goals), default=0.0)
        if err < args.tolerance:
            print(f"  settled within {err:.4f} rad")
            return
    print(f"  holding at {err:.4f} rad of residual droop")


def build_parser() -> argparse.ArgumentParser:
    parser = argparse.ArgumentParser(description="Teach and replay arm poses")
    sub = parser.add_subparsers(dest="cmd", required=True)

    p_save = sub.add_parser("save", help="capture the current pose")
    p_save.add_argument("name")
    p_save.set_defaults(func=_cmd_save)

    p_list = sub.add_parser("list", help="list taught poses")
    p_list.set_defaults(func=_cmd_list)

    p_del = sub.add_parser("delete", help="remove a pose")
    p_del.add_argument("name")
    p_del.set_defaults(func=_cmd_delete)

    p_lim = sub.add_parser(
        "limits", help="emit robot.yaml soft limits spanning the taught poses"
    )
    p_lim.add_argument(
        "--margin",
        type=float,
        default=0.10,
        help="radians of headroom beyond the taught extremes (default 0.10)",
    )
    p_lim.set_defaults(func=_cmd_limits)

    p_go = sub.add_parser("go", help="move to a taught pose")
    p_go.add_argument("name")
    p_go.add_argument(
        "--speed",
        type=float,
        default=0.5,
        help="radians per second the streamed setpoint advances (default 0.5)",
    )
    p_go.add_argument(
        "--max-lag",
        type=float,
        default=0.15,
        help="radians the arm may trail its setpoint before it counts as not "
        "keeping up (default 0.15)",
    )
    p_go.add_argument(
        "--stall-time",
        type=float,
        default=1.5,
        help="seconds of sustained lag before stopping (default 1.5)",
    )
    p_go.add_argument(
        "--tolerance",
        type=float,
        default=0.06,
        help="radians of residual error treated as settled (default 0.06)",
    )
    p_go.add_argument("--timeout", type=float, default=5.0)
    p_go.set_defaults(func=_cmd_go)
    return parser


def main() -> None:
    args = cli.parse(build_parser())

    rclpy.init()
    node = PoseClient()
    spinner = cli.spin_background(node)
    try:
        args.func(node, args)
    except KeyboardInterrupt:
        print("\ninterrupted", file=sys.stderr)
    finally:
        cli.shutdown(node, spinner)


if __name__ == "__main__":
    main()

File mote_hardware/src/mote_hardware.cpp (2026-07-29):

#include "mote_hardware/mote_hardware.hpp"

#include <algorithm>
#include <cerrno>
#include <chrono>
#include <cmath>
#include <cstring>
#include <limits>
#include <stdexcept>
#include <thread>

#include "hardware_interface/types/hardware_interface_type_values.hpp"
#include "rclcpp/rclcpp.hpp"

#include "mote_hardware/port_guard.hpp"

namespace mote_hardware
{

namespace
{

rclcpp::Logger logger()
{
  return rclcpp::get_logger("MoteHardware");
}

bool has_command_interface(
  const hardware_interface::ComponentInfo & joint, const std::string & type)
{
  return std::any_of(
    joint.command_interfaces.begin(), joint.command_interfaces.end(),
    [&type](const auto & iface) {return iface.name == type;});
}

std::string joint_param(
  const hardware_interface::ComponentInfo & joint, const std::string & key)
{
  const auto it = joint.parameters.find(key);
  if (it == joint.parameters.end()) {
    throw std::runtime_error(
            "arm joint '" + joint.name + "' is missing the <param name=\"" + key +
            "\"> tag — it should come from robot.yaml via mote.urdf.xacro");
  }
  return it->second;
}

// EEPROM writes need a moment to settle; the wheel path relies on the SDK's own
// pacing, but the arm re-reads to verify, and an immediate read-back races the
// relock (see mote_arm/README.md — a single read can return a garbled byte and
// make a successful write look failed).
void settle()
{
  std::this_thread::sleep_for(std::chrono::milliseconds(15));
}

}  // namespace

hardware_interface::CallbackReturn MoteHardware::on_init(
  const hardware_interface::HardwareComponentInterfaceParams & params)
{
  if (hardware_interface::SystemInterface::on_init(params) !=
    hardware_interface::CallbackReturn::SUCCESS)
  {
    return hardware_interface::CallbackReturn::ERROR;
  }

  serial_port_    = info_.hardware_parameters.at("serial_port");
  baud_rate_      = std::stoi(info_.hardware_parameters.at("baud_rate"));
  left_id_        = std::stoi(info_.hardware_parameters.at("left_wheel_id"));
  right_id_       = std::stoi(info_.hardware_parameters.at("right_wheel_id"));
  velocity_scale_ = std::stod(info_.hardware_parameters.at("velocity_scale"));
  acceleration_   = std::stoi(info_.hardware_parameters.at("acceleration"));

  // Joints are classified by what they are commanded with, not by position in
  // the list: the wheels take velocity, the arm takes position. That keeps the
  // URDF free to list them in any order and makes a mis-declared joint an
  // error here rather than a servo driven in the wrong mode.
  std::vector<std::size_t> wheels;
  std::vector<std::size_t> arm;
  for (std::size_t i = 0; i < info_.joints.size(); ++i) {
    const auto & joint = info_.joints[i];
    if (has_command_interface(joint, hardware_interface::HW_IF_VELOCITY)) {
      wheels.push_back(i);
    } else if (has_command_interface(joint, hardware_interface::HW_IF_POSITION)) {
      arm.push_back(i);
    } else {
      RCLCPP_ERROR(
        logger(), "Joint '%s' declares no velocity or position command interface",
        joint.name.c_str());
      return hardware_interface::CallbackReturn::ERROR;
    }
  }

  if (wheels.size() != 2) {
    RCLCPP_ERROR(
      logger(), "Expected 2 velocity-commanded wheel joints, got %zu", wheels.size());
    return hardware_interface::CallbackReturn::ERROR;
  }
  wheel_joint_index_ = {wheels[0], wheels[1]};

  if (
    info_.joints[wheel_joint_index_[LEFT]].name != "left_wheel_joint" ||
    info_.joints[wheel_joint_index_[RIGHT]].name != "right_wheel_joint")
  {
    RCLCPP_WARN(
      logger(),
      "Unexpected wheel joint order: '%s', '%s' "
      "(expected left_wheel_joint, right_wheel_joint)",
      info_.joints[wheel_joint_index_[LEFT]].name.c_str(),
      info_.joints[wheel_joint_index_[RIGHT]].name.c_str());
  }

  if (!arm.empty()) {
    const auto speed = info_.hardware_parameters.find("arm_moving_speed");
    const auto acc = info_.hardware_parameters.find("arm_moving_acc");
    if (speed != info_.hardware_parameters.end()) {
      arm_moving_speed_ = std::stoi(speed->second);
    }
    if (acc != info_.hardware_parameters.end()) {
      arm_moving_acc_ = std::stoi(acc->second);
    }
  }

  for (const std::size_t i : arm) {
    const auto & joint = info_.joints[i];
    try {
      ArmJoint spec;
      spec.name = joint.name;
      spec.id = std::stoi(joint_param(joint, "id"));
      spec.min_rad = std::stod(joint_param(joint, "min"));
      spec.max_rad = std::stod(joint_param(joint, "max"));
      spec.zero_counts = std::stoi(joint_param(joint, "zero"));
      spec.sign = joint_param(joint, "invert") == "true" ? -1 : 1;
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

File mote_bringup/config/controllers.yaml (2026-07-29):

controller_manager:
  ros__parameters:
    update_rate: 50

    diff_drive_controller:
      type: diff_drive_controller/DiffDriveController

    joint_state_broadcaster:
      type: joint_state_broadcaster/JointStateBroadcaster

    # The SO-101 arm. Loaded but spawned *inactive* (see launch_utils): claiming
    # the position command interfaces is what enables servo torque, so the arm
    # is back-drivable until something explicitly asks it to hold.
    arm_controller:
      type: joint_trajectory_controller/JointTrajectoryController

diff_drive_controller:
  ros__parameters:
    # wheel_separation and wheel_radius come from mote_description/config/robot.yaml,
    # injected at launch by mote_launch.py
    left_wheel_names: ["left_wheel_joint"]
    right_wheel_names: ["right_wheel_joint"]

    linear:
      x:
        max_velocity: 0.3
        max_acceleration: 1.0
        max_deceleration: -1.0
    angular:
      z:
        max_velocity: 1.87
        max_acceleration: 5.0
        max_deceleration: -5.0

    # The deadman for remote teleop, pinned rather than left to the default: the
    # wheels halt this long after the last command, so an operator whose link
    # drops mid-drive stops on the robot's own clock instead of running on. A
    # teleop source must publish faster than this or the robot stutters between
    # commands — the shipped Foxglove layout uses 10 Hz.
    cmd_vel_timeout: 0.5

    odom_frame_id: odom
    base_frame_id: base_footprint
    enable_odom_tf: false       # odom->base is owned by kinematic_icp; wheel
                                # odom reaches it via the odom_tf_relay leaf

    # Covariance for a 2D robot — z/roll/pitch are constrained
    pose_covariance_diagonal:  [0.001, 0.001, 0.001, 0.001, 0.001, 0.01]
    twist_covariance_diagonal: [0.001, 0.001, 0.001, 0.001, 0.001, 0.01]

arm_controller:
  ros__parameters:
    # `joints` comes from mote_description/config/robot.yaml (arm.joints),
    # injected at launch by mote_launch.py — the same treatment the wheel
    # geometry gets, so robot.yaml stays the single source of truth.
    command_interfaces: ["position"]
    state_interfaces: ["position"]

    # The servos close their own position loop, and MoteHardware reads arm
    # state one joint per cycle (~8 Hz per joint) to stay inside the bus budget
    # it shares with the wheels. Generating the trajectory from the last
    # commanded point rather than from that deliberately-lagging state is what
    # keeps the two consistent.
    open_loop_control: true

    # Jog moves one joint at a time; the rest hold where they are.
    allow_partial_joints_goal: true

    # No tolerance checking: the authoritative limits are the per-joint soft
    # limits enforced in the hardware, and a goal-time check against 8 Hz
    # feedback would fail trajectories that in fact completed.
    constraints:
      stopped_velocity_tolerance: 0.0
      goal_time: 0.0

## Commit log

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2026-05-01 feat: add keyboard teleop and working bringup stack
    - Replace placeholder XML launch with full Python launch file
    - Add controllers.yaml for diff_drive_controller (50 Hz, correct wheel geometry)
    - Add teleop_twist_keyboard with TwistStamped remapping (ros2_controllers 4.x requires stamped)
    - Fix serial port: /dev/ttyUSB0 → /dev/ttyACM0 for servo controller
    - Improve serial port error message with actionable diagnostic hint
    - Add ros2run and teleop-twist-keyboard dependencies to pixi.toml
    [auldbot.urdf.xacro, controllers.yaml]
2026-05-01 feat: bring up all sensors with stable device names and full rviz support
    - Replace rplidar_ros with sllidar_ros2 (third_party submodule) — the legacy
    driver does not support the RPLIDAR C1; Standard scan mode, 16 m range
    - Add udev rules giving stable /dev/auldbot_servos, /dev/auldbot_lidar,
    /dev/auldbot_camera symlinks matched by USB serial number
    - Move ros2_control hardware params (serial port, IDs, velocity scale) out of
    the URDF into the launch file via xacro args, keeping the URDF as a pure
    physical description
    - Fix TF tree: set base_frame_id to base_footprint so diff_drive_controller
    publishes odom→base_footprint, avoiding base_link having two parents
    - Add slam_toolbo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
    [auldbot.urdf.xacro, controllers.yaml]
2026-05-01 feat(nav2): add Nav2 navigation stack
    Add nav2_params.yaml tuned for auldbot (0.12 m robot radius, 0.3 m/s
    max velocity, MPPI controller, TwistStamped output) and nav2_launch.py
    with lifecycle manager. Update rviz config with Nav2 panel, goal tool,
    global plan path display, and costmap overlays. Fixed frame set to map.
    Add `pixi run nav` task.
2026-05-02 fix(bringup): unwrap FindExecutable from PathJoinSubstitution
    FindExecutable already returns a full path — wrapping it in
    PathJoinSubstitution produces an unresolved object on some platforms,
    breaking launch on aarch64.
2026-05-02 fix(bringup): replace substitution chain with ament_index path resolution
    FindExecutable + PathJoinSubstitution doesn't resolve correctly on
    aarch64. Use ament_index_python and os.path.join instead to build
    the xacro command at launch time.
2026-05-02 fix(deps): add ros-jazzy-xacro to base dependencies
    xacro is required to process the URDF at launch time but was only
    available via ros-jazzy-desktop in the dev environment.
2026-05-02 feat(bringup): add robot combined launch, systemd units, and WiFi optimisations
    Add robot_launch.py combining hardware/slam/nav for single-command
    bringup. Add per-component systemd services with correct dependencies.
    Add image_transport_plugins for compressed camera over WiFi and
    cyclonedds.xml for unicast peer discovery. Add install-systemd and
    sync pixi tasks.
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2026-05-05 fix: motor directions set up correctly
    [controllers.yaml]
2026-05-05 fix: lidar was rotateed by 180 degrees
    [auldbot.urdf.xacro]
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2026-05-05 fix: measured and corrected all calibrations
    [auldbot.urdf.xacro, controllers.yaml]
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2026-05-29 Big cleanup before making public
    Cleaned up unused files, spelling mistakes, and general formatting.
    Added more complete build instructions.
    [SO Base ORP.step, SO Base ORP.stl]
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2026-06-12 Add CLAUDE.md. Fix bringup duplication.
    [controllers.yaml, mote.urdf.xacro, robot.yaml]
2026-06-12 Add comment to controllers to avoid confusion
    [controllers.yaml]
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2026-06-12 Add use_sim branch to URDF: gz_ros2_control + simulated lidar
    With use_sim:=true the ros2_control hardware plugin swaps from
    MoteHardware to gz_ros2_control/GazeboSimSystem, the gz_ros2_control
    system plugin is attached (controller params file passed via the
    sim_controllers_file arg), the fixed caster becomes frictionless, and a
    gpu_lidar matching the RPLIDAR C1 (specs added to robot.yaml under
    lidar.sim) publishes in lidar_scan_link like the real driver.
    Without the flag the xacro output is byte-identical to before, and the
    sim output converts cleanly with 'gz sdf -p'.
    [mote.urdf.xacro, robot.yaml]
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2026-06-23 Split robot launch: mapping (bringup+SLAM) vs robot (bringup+nav) (#10)
    Rename the `robot` task to `mapping` (bringup + slam_toolbox) and repurpose
    `robot` to mean everyday operation: bringup + Nav2 against a saved map.
    - mote_bringup/launch/robot_launch.py: now composes mote_launch + nav2_launch,
    forwarding a `map` arg defaulting to ~/.mote/map.yaml
    - mote_bringup/launch/mapping_launch.py: the former robot_launch.py contents
    (mote_launch + slam_launch), unchanged
    - pixi.toml: add `mapping` task; `robot` now resolves to the new composition
    - CLAUDE.md/README: update launch hierarchy and task docs; correct the stale
    "localization_launch.py — AMCL-based" note (it is kinematic_icp odom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
2026-06-25 Lidar-odometry localization + dedicated mote_simulation package (#11)
    Localization (shared by the real robot and the sim):
    - kinematic_icp owns the odom->base transform; wheel odometry reaches it
    as a motion prior via a new odom_tf_relay node, which republishes the
    inverted wheel pose as a base_footprint->odom_wheel leaf
    - localization_launch.py runs both nodes and accepts use_sim_time
    - diff_drive_controller no longer publishes the odom TF (enable_odom_tf:
    false) since kinematic_icp now owns that edge
    Simulation:
    - move sim_launch.py, the worlds, and the smoke test out of mote_bringup
    into a new workstation-only mote_simulation package (excluded from the
    robot sync, built only in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
    [controllers.yaml, mote_world.sdf, office_world.sdf]
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2026-06-29 Add a hard hospital simulation world and its generator (#15)
    Adds a third, "hard" tier to the gz sim worlds, above mote_world (easy) and
    office_world (medium): a ~58x38 m hospital with a looping corridor grid, ~50
    rooms, and furniture clutter. It stacks the failure modes the easier worlds
    isolate -- aperture-problem drift on corridors past the lidar range and false
    loop closures from dense near-identical wards -- and adds genuine navigable
    loops so SLAM must get real loop closures right and Nav2 has path choices.
    The world is produced by a committed generator, gen_hospital.py: you describe
    the layout in room/corridor terms and it computes the wall segments, cuts the
    doorways, and emits the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
    [hospital_world.sdf]
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2026-06-29 feat: Bag recorder (#17)
    * Add rosbag recording task with 10-minute splits
    `pixi run record` (record_launch.py) records the perception-relevant topics —
    compressed image, camera_info, tf, and filtered scan — to a timestamped dir
    under ~/.mote/bags, split into 10-minute segments (--max-bag-duration; override
    with split:=). Adds the ros2bag CLI verb, the recorder, and the mcap storage
    plugin to the robot env, which were absent.
    * Make recording production-ready: dual streams, disk caps, autostart
    Replace the single rosbag recorder with two purpose-split streams written
    under ~/.mote/bags: a light "min" stream (lidar + TF, 10-minut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
2026-07-06 Add a one-shot Pi setup task; disable WiFi power save (#22)
    pixi run setup now runs the once-per-Pi configuration in one go: udev
    rules (plus the dialout group, previously a manual usermod), the
    NetworkManager drop-in that disables WiFi power save (the Broadcom
    driver's SDIO stalls hang SSH sessions otherwise), and the systemd
    services. The README's Pi section shrinks to the one command, and
    pixi.toml groups tasks by purpose with the feature-scoped tasks
    together.
2026-07-06 Capture cmd_vel, goals, and system health in recorded bags (#23)
    Debugging why real-robot nav underperforms sim showed the lite bags
    had no commanded velocity or goal, so there was no way to tell
    whether Nav2 was asking for more than the base could deliver or the
    base was stalling under load. Record cmd_vel, odom, goal_pose, plan,
    and task command/status, and add a system_monitor node publishing
    /diagnostics (cpu/mem/load/temp, and on a Pi the firmware
    under-voltage/throttle flags) since the robot has no battery
    state-of-charge telemetry to fall back on.
    Claude-Session: https://claude.ai/code/session_01AKSfStEXVGKLj16b922262
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2026-07-06 Log which record streams and topics are actually active at launch (#25)
    Debugging today's bag gap showed the console gives no indication of
    what record_launch.py is doing -- ros2 bag record only logs per-topic
    subscribe events, so a stream running with a stale (pre-sync) topic
    list looks identical to one running correctly until you inspect the
    bag afterward. Print the active streams and each stream's output path
    and topic count/list up front.
    Claude-Session: https://claude.ai/code/session_01C1uzkSYe5pzhPvamaoaHcW
2026-07-06 Fix Nav2 bringup abort (AMCL initial pose) + skip per-frame camera conversion (#26)
    * Fix Nav2 bringup abort: auto-set AMCL initial pose at launch
    set_initial_pose was false, so AMCL never published map->odom until a
    human set an initial pose in RViz. global_costmap's 60s transform wait
    timed out first, causing lifecycle_manager_navigation to abort the
    entire nav bringup (bt_navigator etc. permanently inactive, rejecting
    all goals) well before anyone got a chance to set the pose manually.
    Default the initial pose to the map origin (0,0) so AMCL localizes on
    its own at startup.
    Also:
    - Match the Particle Cloud display's RViz QoS to AMCL's actual
    publisher QoS (best effort), fixing a silen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
2026-07-07 Add DWB WheelSpeedLimitCritic to reject infeasible (v, ω) samples (#28)
    * Add DWB WheelSpeedLimitCritic to reject infeasible (v, w) samples
    DWB samples a v x w rectangle with no notion of the differential-drive
    coupling between linear and angular velocity, so it commands (v, w) pairs
    that need a wheel faster than the STS3215 servo can turn (~0.218 m/s). The
    robot then under-rotates through curves and drifts off the path.
    mote_nav is a new ament_cmake package providing WheelSpeedLimitCritic, a
    dwb_core::TrajectoryCritic that throws IllegalTrajectoryException for any
    trajectory whose outer-wheel speed |v| + (S/2)|w| exceeds max_wheel_speed,
    so DWB only ever commands achievable velocities. T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
    [robot.yaml]
2026-07-07 Fix /particle_cloud RViz display type (record spam) (#31)
    AMCL publishes /particle_cloud as nav2_msgs/msg/ParticleCloud, but the
    RViz "Particle Cloud" display used rviz_default_plugins/PoseArray, which
    subscribes declaring geometry_msgs/msg/PoseArray. Two types on one topic
    made rosbag2 refuse it ("more than one type associated"), and the display
    never rendered (type mismatch dropped every message).
    Switch to nav2_rviz_plugins/ParticleCloud so the subscription type matches
    the publisher; add the plugin as an explicit dev dependency (it was already
    pulled in transitively via nav2-bringup).
    Claude-Session: https://claude.ai/code/session_01WqxXf7S3GaoMZ1yFABRTgu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
2026-07-08 Add committed sim site bundles (SLAM maps) for the three worlds (#33)
    sim-nav had no map to localise against: robot_launch defaulted the map to
    the active site in the robot's real ~/.mote, which on a workstation is empty
    or belongs to a different place. Each sim world now owns a committed Site
    bundle so `pixi run sim-nav world:=X` drives X's own map.
    - sim_home/: an in-repo sim MOTE_HOME with one Site per world (site name ==
    world stem, floor `ground`), holding that world's map + zones. The sim pixi
    env points MOTE_HOME here ([feature.sim.activation.env]); sim_launch nav
    mode resolves the map from the world arg and passes it to robot_launch, so
    it never falls back to the robot's ~/.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
2026-07-17 Camera driver research: keep v4l2_camera, don't switch to usb_cam (#19) (#36)
    Measured on the Pi under pixi run launch: current v4l2_camera YUYV
    passthrough costs 0.5%/core idle, 14.7%/core with a compressed consumer
    at 61C — the camera is not straining the Pi. usb_cam's native MJPEG
    passthrough (the motivating feature) is broken in 0.8.1 and on upstream
    main (pixel_format name mismatch, issue #346 / unmerged PR #378, plus
    fixed-size message padding), and its working configs only win by capping
    the frame rate. Full numbers and integration-cost notes in the report.
    Claude-Session: https://claude.ai/code/session_01JiLWRia6sjtJvZ6ksrLw8f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
2026-07-23 Review, rebase and land the l2-semantics branch (open-vocab fetch) (#44)
    * Add L2 semantics: fetch objects by open-vocabulary label
    An OWLv2 detection server (pixi depth env, query labels ride in each
    request) feeds a torch-free object_detector_node that grounds each bbox
    bottom-centre through the floor plane and publishes map-frame poses at
    the capture stamp. The fetch grammar accepts an object label wherever a
    zone name doesn't match; the new AcquireObject behaviour asks the
    detector and writes a standoff goal to the same object_pose blackboard
    seam, so the rest of the tree is unchanged. The detector idles with no
    image subscription until a label is set. Client plumbing is shared with
    the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
    [mote_world.sdf]
2026-07-23 Sim benchmark harness: score missions against Gazebo ground truth (#45)
    * Add sim benchmark harness scoring nav missions vs Gazebo ground truth
    Runs scripted NavigateToPose missions in the headless sim and emits objective
    metrics, so Nav2/SLAM/localization changes can be measured rather than eyeballed.
    Built as the reusable base for the planned parameter-sweep tool and the future
    IMU study, so the metric maths is a ROS-free module an offline bag scorer can
    share.
    - mote_simulation/tools/benchmark/
    - metrics.py: ATE (rigid SE(2) alignment), goal success/time, clearance,
    smoothness (jerk/reversals), recovery counts, aggregation. numpy-only, no ROS.
    - record.py: one-trial rclpy client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
    [mote.urdf.xacro]
2026-07-23 Research: SfM / multi-view depth as an improvement or replacement for single-image Depth Anything (#40)
    * Research: SfM / multi-view depth vs single-image Depth Anything (issue #21)
    Literature pass and feasibility triage for replacing or augmenting the L1
    single-image depth path with odometry-scaled multi-view geometry. Key
    findings: the off-board depth server is CPU-only, which rules out the
    DUSt3R/MASt3R/VGGT pointmap family outright; the pitched-down floor-band
    geometry makes forward-motion parallax workable on paper; and the
    perception record stream already captures everything an offline
    feasibility harness needs. Recommends a staged plan: bag-based geometry
    feasibility harness first, t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
2026-07-24 Add a `goto <zone>` command and optional area footprints to zones (#46)
    Adds place-based navigation ("go to the kitchen") to the task layer. Rather
    than a separate "region" concept, this treats a named place as one thing — a
    **zone** — since a zone and a region are both just a named pose you navigate
    to. A zone is a pose (a fetch waypoint or a `goto <zone>` target) that MAY
    carry an optional area **footprint**, which turns it into a room and answers
    "am I inside it". `goto` and `fetch` resolve names against the one zones table.
    - mote_tasks/zones.py: load_zones returns {name: Zone(name, pose, footprint)}.
    The footprint is a Circle (`radius`) today, chosen in _footprint() with a
    clea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
2026-07-26 Scope DDS discovery traffic: localhost sims, per-run domains, robot NIC pin (#54)
    Default CycloneDDS discovery makes every participant announce itself on
    every interface, so a sim on the workstation is discoverable by anything
    on the LAN, two benchmark jobs on one machine share a graph, and the Pi
    chatters on interfaces that carry no ROS traffic. Three scopes, three
    fixes:
    - Sim/benchmark: the `sim` pixi environment sets
    ROS_AUTOMATIC_DISCOVERY_RANGE=LOCALHOST, so every sim, benchmark and
    sweep participant confines discovery to the host it runs on. Visibility
    is one-way (a LOCALHOST participant still finds same-host default-range
    ones, not the reverse), hence the new `rviz-sim` task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
2026-07-26 M2: Foxglove observability + teleop (#64)
    * Fleet M2: Foxglove observability and remote teleop
    An operator can now watch and drive one robot from anywhere on the tailnet,
    and the robot's ROS graph finally stops leaving the robot.
    foxglove_bridge runs on the robot and Foxglove connects to ws://<robot-id>:8765.
    It is included in the base bringup by default, on the health monitor's pattern
    and for the health monitor's reason: every way of starting the robot should give
    someone a way to look at it. Under systemd it is a separate unit instead --
    mote-bringup.service passes foxglove:=false -- because the view has to outlive a
    bringup restart, and a crash-looping mission is exactly when you want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
    [controllers.yaml]
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2026-07-27 Does Mote need an IMU? Checked against real bags: no (#56)
    * Benchmark: score dead-reckoning separately, and add a wheel-friction knob
    Two additions to the sim benchmark harness, both useful independently of what
    prompted them.
    Odometry ATE: record.py now samples the odom->base pose alongside map->base, and
    metrics.py reports its ATE against ground truth as `odometry.*`. The existing
    localization ATE goes through AMCL's map correction, which masks changes in the
    odometry underneath it; this isolates odometry quality on its own, which is what
    you want when tuning kinematic_icp or sweeping localization params. report.py
    surfaces it in both the aggregate and per-trial tables.
    Wheel friction: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
    [mote.urdf.xacro]
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2026-07-28 Arm servo gains: Kp=16 and Ki=0 cause permanent position droop (corrects task 233) (#68)
    * Measure arm servo gains instead of guessing them: arm-gains sweep
    Kp=32 landed with the arm bring-up on the strength of two hand-run points
    (Kp=16 -> 0.071 rad short, Kp=32 -> 0.033 rad, load flat near 190/1000).
    That was enough to identify proportional droop and rule out the 5 V supply,
    but not enough to pick a gain: nothing measured what 64 or 128 do, and
    nothing checked the failure mode that bounds the top of the range, a servo
    that hunts around its goal instead of holding it.
    `arm-gains sweep` is that measurement, alongside `show`/`apply` because it
    is the same source-of-truth story: gains live i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
    [robot.yaml]
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2026-07-29 Report wheel slip and stuck robots from the odometry residual (#77)
    kinematic_icp takes wheel odometry as its prior and corrects it against the
    scan, so the correction is already a measurement of how wrong the wheels were.
    Task 165 established the quiet baseline is tight enough for an event to stand
    out — and that this is why the BNO085 is not justified. This turns that signal
    into a live health check.
    slip_monitor compares the travel each source reports over a 1 s sliding window,
    in the body frame, and publishes `slip` / `stuck` / `icp_fault` as the `slip`
    status on /diagnostics, which health_monitor now folds into the robot roll-up
    alongside system_monitor's. All three are DEGRADED, nev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
    [slip.yaml]
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2026-07-30 Gate kinematic_icp output against max_wheel_speed (reject impossible pose jumps) (#78)
    * Gate kinematic_icp against the drive envelope
    Real mapping bags catch the scan match emitting, in a single scan, motion the
    drive cannot produce: up to 1.2 m/s against a measured 0.218 m/s limit, once
    0.12 m while the wheels reported the robot stationary. Slip cannot cause it in
    that direction, since slip makes the wheels over-read and never the lidar.
    The frames are rare (10 in 25 minutes) and always isolated, so the first
    question was whether they matter. They do. The ICP-vs-wheel gap rate is the
    same either side of an excursion, so the displacement is never given back:
    these are steps, not spikes, a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
    [wheel_speed.hpp]
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2026-07-31 Move jog and arm-pose onto the shared CLI plumbing (they abort on exit today) (#85)
    Both tools destroy their node while rclpy.spin() still holds it, which pulls
    the executor out from under itself: the interpreter calls std::terminate and
    the process exits 134 with "terminate called without an active exception" —
    after the tool has already done its work. So the run succeeds and the operator
    sees a crash.
    This was believed latent. It is not. With no stack running to talk to, `jog`
    (stdin closed) and `arm-pose list` each aborted 3 of 3 runs on this branch's
    parent, and exit 0 on 3 of 3 after. The 0.2 s sleep that used to mask it in
    jog went away with the ros2_control fold (#74), so nothing h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
    [arm_pose.py, cli.py]
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2026-08-12 Cut monitor-node CPU, and measure what the cost actually is (#96)
    health_monitor and task_server were measured at 22% and 14-20% of a core on
    mote-01 during a nav mission, for logic that runs at 1-10 Hz. The premise was
    that they pay to deserialize high-rate messages. They do not, much: measured on
    the robot, deserialization is 13% of what a subscription costs and the rclpy
    wake-up is the other 87%.
    Both sanctioned Python fixes land, because both are free and both are real,
    paired against the unpatched build running at the same instant:
    health_monitor raw=True on the watched topics 18.1 -> 17.1
    task_server idle tick 10 Hz -> 1 Hz 7.8 -> 6.9
    The watches only count arriv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
    [ab-patched-vs-unpatched.csv, after-joints50.csv, before-idle.csv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]
2026-08-12 map_cleanup: phantom orientations — picker scores height, not prominence (#97)
    * map_cleanup: keep the energy panel's peak labels clear of the title bar
    The angle labels were drawn with their baseline at y=22 under the 18 px
    title bar that _label() paints over the finished panel, hiding their top
    halves; the right-edge reserve was also too narrow for three digits.
    Claude-Session: https://claude.ai/code/session_013o39JoxarofwaPi6kGYxXY
    * map_cleanup: pick wall directions above the broadband floor, not above zero
    The declutter pass kept any local maximum of the angular energy reaching
    0.45 of the global maximum. Clutter puts energy a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
    [cli.py]
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2026-09-01 health_monitor in C++: the wake-up is the cost, and it includes /tf (#109)
    Task 365 measured an rclpy wake-up at ~0.78 ms of CPU per message, of which
    deserializing the payload is 13%. health_monitor consumes ~152 msg/s, so ~12
    points of a core went before it did anything with them, against a 5-point
    budget. The two sanctioned Python fixes were worth ~1 point each; the rest
    needed a language.
    The lever is the count of wake-ups, so /tf is part of the port rather than an
    exception to it: a TransformListener takes the whole /tf stream whatever
    handful of edges the node asks about, 4.8 of the Python node's 16.9 points.
    New package mote_health, because mote_bringup is ament_python and mote_nav'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
    [paired-idle.csv, paired-loaded.csv, paired-real-payloads.csv]
2026-09-02 Zones are no longer taught only by driving: unbound remedies, editor anchor provenance (#112)
    The zone layer was written when a zone got geometry one way: a robot was
    driven there and `save-zone` captured the pose. `segment-map` and the
    dashboard's zone editor have since added two more, and M4 made a binding
    travel inside a map revision, so a robot can hold geometry for a floor it has
    never entered. Five behaviours and about sixty prose sites still said
    otherwise.
    **`unbound` is a fact about the revision, not about where the robot has been.**
    The goto/fetch refusal, `task_server`'s boot warning, `site info` and
    `bundle.validate`'s warning each said the remedy was to drive there. They now
    na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
    [poses.py]
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
